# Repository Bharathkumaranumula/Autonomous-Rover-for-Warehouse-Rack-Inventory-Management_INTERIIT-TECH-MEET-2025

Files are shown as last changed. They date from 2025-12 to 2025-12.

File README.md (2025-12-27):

# Autonomous Rover for Warehouse Rack Inventory Management

## About the Project
This project was developed as part of **Inter IIT Tech Meet 14.0** under the problem statement **“Autonomous Rover for Warehouse Rack Inventory Management.”**  
The objective was to design and build an autonomous wheeled robot capable of navigating warehouse aisles and performing **reliable vertical inventory scanning up to 2 meters**.

The system aims to replace slow, unsafe, and error-prone manual inventory audits with a compact, accurate, and scalable robotic solution suitable for modern warehouse environments.

---

## My Contribution
I was responsible for the **entire hardware design and implementation** of this project. My role covered the complete hardware lifecycle, including mechanical design, structural layout, drive system selection, Z-axis scissor lift design, power system architecture, safety mechanisms, and hardware integration.

I along with my hardware team led the hardware development from problem understanding and calculations through CAD design, fabrication, assembly, and testing, ensuring the system met competition constraints and performed reliably during integrated operation.

---

## Problem Statement Summary
Modern warehouses face several challenges:
- Manual inventory audits take **10–15 minutes per rack**
- Human errors lead to **30–50% stock mismatches**
- Ladder-based high-rack inspections are unsafe
- Inventory data lacks real-time visibility

The robot must:
- Navigate narrow warehouse aisles autonomously
- Detect and align with storage racks
- Perform vertical scanning across multiple shelf levels (up to ~2 m)
- Reliably capture QR-based inventory data
- Operate safely within strict size and weight constraints

---

## Proposed Solution
The solution is a **compact autonomous differential-drive rover** equipped with a **centrally mounted multi-stage scissor lift** for vertical scanning.

Key system capabilities include:
- Autonomous indoor navigation
- Vertical scanning up to ~1.8–2.0 m
- High QR scanning accuracy
- Modular mechanical and electrical design
- Robust safety and fail-safe mechanisms

---

## System Overview
- Robot type: Autonomous wheeled mobile robot  
- Drive type: Differential drive (2 powered wheels + 2 ball casters)  
- Vertical actuation: Four-stage scissor lift  
- Maximum scanning height: ~1.8–2.0 m  
- Total system mass: ~20 kg  
- Footprint: 570 × 355 mm  
- Compute: NVIDIA Jetson AGX Xavier  
- Low-level control: ESP32  

---

## Hardware Architecture

### 1. Chassis and Structural Design
- Dimensions: **570 × 355 × 145 mm**
- Ground clearance: **25 mm**
- Total mass: **≈ 20 kg**
- Material: **6062 aluminium T-slot profiles (20 × 20 mm)**
- Closed-box frame topology for improved stiffness
- Low and centrally placed mass for anti-tip stability
- Modular mounting surfaces for rapid iteration

---

### 2. Locomotion System (X–Y Motion)
- Drive configuration: **2-wheel differential drive**
- Support: Front and rear metal ball casters
- Turning radius: **0 mm (on-the-spot rotation)**
- Drive wheel diameter: **100 mm**
- Wheel width: **25 mm**
- Motors: **RMCS 2012 DC motors**
  - Voltage: 18 V  
  - Gearbox: 1:25 planetary  
  - Rated torque: 39 kg·cm  
  - Encoders: ~1300 CPR at wheel  
- Direct-drive layout for minimal backlash
- Stability and torque validated with conservative acceleration limits

---

### 3. Z-Axis Scissor Lift Mechanism
- Mechanism: **Four-stage scissor lift**
- Actuation: Horizontally oriented lead screw
- Camera height range: **~320 mm to ~1780 mm**
- Usable vertical coverage: **~1800 mm**
- Shelf levels supported: **5 discrete heights**
- Vertical accuracy target: **±20 mm**
- Achieved repeatability: **~9–18 mm**
- Anti-sway achieved through symmetric geometry and tight-fit bearings
- Mechanical hard stops and limit switches for safety

---

### 4. Power System
- Three independent Li-Po batteries:
  - Jetson AGX Xavier
  - Drive motors
  - Z-axis motor
- 25C discharge capability
- Power Management Unit (PMU) for regulated distribution
- Electrical isolation between compute and motors
- Live battery monitoring and diagnostics

---

### 5. Control Electronics
- Microcontroller: **ESP32 DevKit-V1**
- Motor drivers: **Cytron MDD20A**
- Encoder-based closed-loop PID control
- UART communication between ESP32 and Jetson
- PCB designed with separate logic and power zones for reliability

---

### 6. Safety Systems
- Electronic kill switch (power cut-off)
- Physical emergency stop (E-stop)
- Z-axis limit switches and bump switch
- Firmware-level command clamping
- Software-triggered emergency stop on fault detection

---

## Hardware–Software Integration
- ESP32 handles real-time motor control and encoder feedback
- Jetson AGX Xavier handles perception, mapping, and planning
- ROS2 hardware interfaces synchronize:
  - X–Y motion
  - Z-axis positioning
  - Scanning tasks
- Closed-loop feedback ensures stable and repeatable operation

---

## Testing and Validation
Hardware validation included:
- Static load and structural stability tests
- Drive torque and acceleration verification
- Full-stroke Z-axis endurance testing
- Vertical positioning repeatability tests
- Integrated navigation + lift + scanning runs

### Key Results
- Vertical repeatability: **≤ 18 mm**
- Platform tilt at maximum lift: **≤ 1.3°**
- QR scanning success rate: **96% first pass, 100% with rescan**
- No jamming or over-current events observed

---

## Key Hardware Highlights
- Horizontally actuated scissor lift within base footprint
- Modular T-slot chassis acting as a mechanical backplane
- Differential drive optimized for stability and control simplicity
- COTS-heavy, serviceable, and student-replicable design
- Hardware decisions driven by safety and testability

---

## Documentation
Detailed mechanical design, calculations, CAD models, testing procedures, and validation results are available in the **attached technical report** provided with this repository.

---

## Acknowledgements
Developed as part of **Inter IIT Tech Meet 14.0** under the **Eternal** problem statement on warehouse automation.

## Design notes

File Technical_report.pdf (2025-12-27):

# Autonomous Rover for Warehouse Rack Inventory Management

## INTER IIT TECH MEET 14.0

## End Term Submission Report

### Team 33

### 1 Executive Summary

### 1.1 Problem Statement

The objective of this project is to develop an autonomous wheeled-mobile robot capable of nav-igating complex warehouse environments while performing reliable vertical scanning operations on storage racks. Modern warehouses require fast, accurate, and automated inventory monitoring across multiple rack levels; however, manual scanning is slow, error-prone, and unsafe when working at elevated heights.

To address this need, the robot must be able to:

- Autonomously traverse warehouse aisles.
- Detect and localize storage racks.
- Capture QR-based inventory information at varying elevations.

A key requirement is the ability to perform vertical scanning up to 2 meters, ensuring full coverage of typical warehouse shelving systems. The system must integrate perception, motion control, vertical actuation, and human–machine interaction while maintaining safe operation, real-time performance, and robust communication within indoor environments.

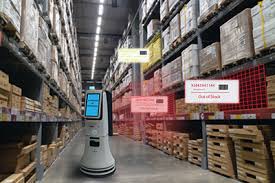
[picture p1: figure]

Figure 1: Inventory Scanning

### 1.2 Proposed Solution

We propose a robust differential-drive two-wheeled robot with a scissor lift mechanism for vertical traversal. The key elements of the solution are:

- Compute and Control
- Industry-grade SBC: Jetson AGX Xavier.
- Microcontroller: ESP32 DevKit for real-time motor control and I/O.

- Supports complex onboard computation and over-the-air software updates.
- 3D Perception
- Intel RealSense D455i RGB-D camera.
- Generates dense depth maps to build dynamic 3D maps of the environment.
- Enables navigation in both known and unknown warehouses.
- Vertical Scanning
- Scissor lift mechanism mounted centrally on the chassis.
- Provides precise vertical motion with high positional repeatability.
- Supports QR scanning at multiple rack levels up to 2 m.
- Integrated, Modular System
- Mechanical, electrical, and software components co-designed for competition constraints.
- Modular interfaces allow future upgrades in perception, control, or lift mechanisms.

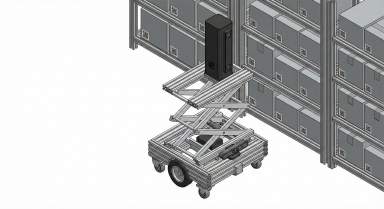
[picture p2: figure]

Figure 2: Proposed Solution

### 1.3 Metrics

Feature | Accuracy / Performance
Lateral Positional Accuracy | ±2 cm
Vertical Positional Accuracy | ±10 cm
QR Scanning Accuracy | 96%
QR Scanning Time (per QR) | 2 s

Table 1: System Metrics

### 1.4 Unique Selling Point / Innovation

- Compact, Competition-Optimized Form Factor
- Rover footprint: 570 × 355 mm, mass ≈ 20 kg.
- Satisfies 600 × 450 × 25 kg competition limits.
- Still accommodates a four-stage lift and dual-camera system.
- Precision Differential Drive
- Two powered wheels plus front and rear ball casters form a diamond-shaped 4-point support polygon.
- Enables zero turning radius and reliable lateral stability near racks.
- Remote Access via Mobile App
- In-house mobile application for robot discovery and connection.
- Provides teleoperation, live video, and inventory data.
- Modular Top Plane
- Top plane supports multiple mounts and toolings.
- Hardware can be reconfigured quickly for different warehouse tasks.

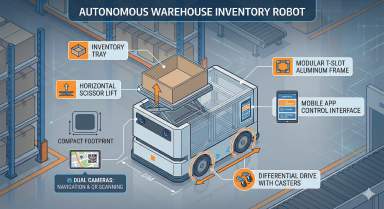
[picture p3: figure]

Figure 3: USPs

### 2 Problem Understanding and Motivation

### 2.1 Challenges Faced in Warehouses

- Inventory Management
- Manual entry and poor tracking in large warehouses.
- Inaccurate inventory counts leading to stockouts and overstocking.

- Labour-Related Issues
- Long walking distances and repetitive tasks cause fatigue and errors.
- Skilled human resources are underutilized on low-skill scanning tasks.
- Large-Scale Operations
- Scaling manual audits across large facilities is difficult and expensive.
- Safety Risks
- High-rack inspection with ladders or lifts is hazardous.
- Interaction with heavy loads and moving equipment increases risk.
- Limited Optimisation
- Human-driven workflows restrict algorithmic optimisation.
- Difficult to systematically improve throughput, safety, and efficiency.
- Data and Visibility Gaps
- No real-time visibility into stock positions.
- Poor analytics for reorder points, KPIs, and performance tracking.

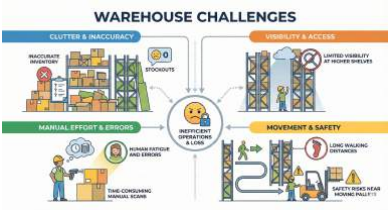
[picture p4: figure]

Figure 4: Warehouse Challenges

### 2.2 Current Solution Gaps

- Slow and Inconsistent Inventory Checks
- Manual audits can take 10–15 minutes per rack.
- Updates are infrequent and often inconsistent.
- High Error and Mismatch Rates
- Human counting introduces 1–3% errors.

- This leads to 30–50% stock mismatches and incorrect replenishments.
- No Real-Time Visibility
- Inventory data is only updated after audits.
- Causes both stockouts and overstocking, hurting service levels.
- Safety and Scalability Limits
- Ladder-based high-rack checks are unsafe.
- Reliance on manual labour makes it hard to scale across warehouses.

Figure 5: Solution Gaps

### 2.3 Value Proposition

- 80% Faster Inventory Audits
- Rover scans racks in under 3 minutes per aisle.
- Reduces manual audit time from 10–15 minutes.
- Enables continuous, near real-time visibility.
- High Scan Accuracy
- > 95% consistency and > 90% QR accuracy.
- Significantly reduces stock mismatches and missed items.
- Operational Uplift
- 4–7% improvement in order fulfilment accuracy.
- Fewer stockouts and better replenishment timing.
- Cost Savings
- Estimated savings of 12–20 lakh per warehouse annually.

- Reduced labour costs, wastage, and discrepancy overheads.
- Safe, Reliable Operation
- Eliminates ladder-based inspections.
- Complies with safety constraints in the problem statement.
- Scalable Deployment
- < 25 kg hardware and 600 mm footprint.
- Can be rolled out across dark stores and distribution centres.
- Digitised Inventory Records
- Generates structured QR-linked logs and 1080p visual datasets.
- Provides a rich base for downstream analytics.
- Future-Ready Infrastructure
- Supports anomaly detection, demand forecasting, and autonomous stock management.
- Aligns with long-term intelligent warehousing roadmap.

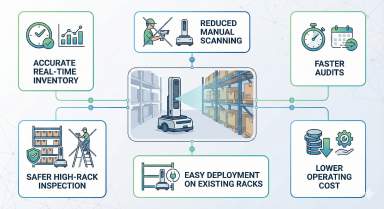
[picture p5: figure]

Figure 6: Value Proposition

### 2.4 Competition Objectives

The major competition objectives are summarised below:

- Navigation and Positioning
- Horizontal positioning accuracy of ±10 cm.
- Vertical positioning accuracy of ±2 cm.
- Obstacle detection within a 5 m range.

- Path planning time under 3 s for real-time operation.
- Emergency stop response under 500 ms.
- Scanning Performance
- Vertical scanning of each rack in less than 3 minutes.
- Image resolution of at least 1920 × 1080 pixels with minimal motion blur.
- Scanning repeatability greater than 95%.
- Detection of 5 × 5 cm QR codes with more than 90% success rate.

Figure 7: Competition Objectives

### 3 System Architecture

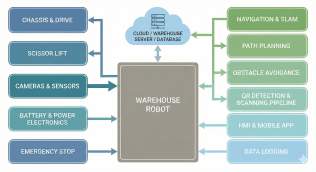
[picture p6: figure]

Figure 8: System Architecture – HW + SW Block Diagram

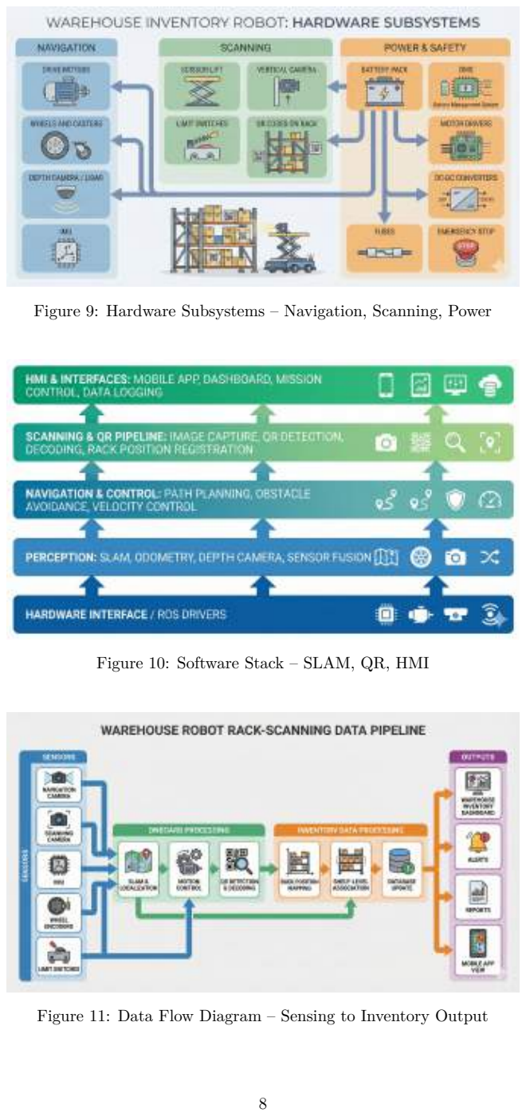
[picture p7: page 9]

Figure 9: Hardware Subsystems – Navigation, Scanning, Power

Figure 10: Software Stack – SLAM, QR, HMI

Figure 11: Data Flow Diagram – Sensing to Inventory Output

### 4 Hardware Design

### 4.1 Chassis and Overall Layout

The chassis is designed to satisfy footprint, mass, and stability constraints while providing a rigid base for the drive and lift subsystems. This ensures safe navigation in narrow aisles while supporting the full lift height.

- Footprint and Mass
- Dimensions: 570 × 355 × 145 mm with 25 mm ground clearance.
- Total mass: ≈ 20 kg, within 600 × 450 × 25 kg competition limits.
- Compact footprint improves aisle compatibility while maintaining stability.
- Frame Construction
- 20 × 20 mm anodised 6062 aluminium T-slot profiles.
- Joints implemented using L-clamps and M4 hammer bolts.
- T-slots support flexible mounting and rapid reconfiguration.
- Closed-Box Topology
- Two structural faces (top and bottom) connected by eight vertical members.
- Closed-box layout improves bending and torsional stiffness.
- Avoids complex diagonal bracing and simplifies fabrication.
- Operating Envelope and Stability
- Heavy components placed low and centrally to maintain a low centre of gravity.
- Geometry tuned for anti-tip behaviour even with the lift extended.
- Compatible with typical warehouse rack spacing and aisle widths.

Figure 12: Chassis CAD with motor mounts

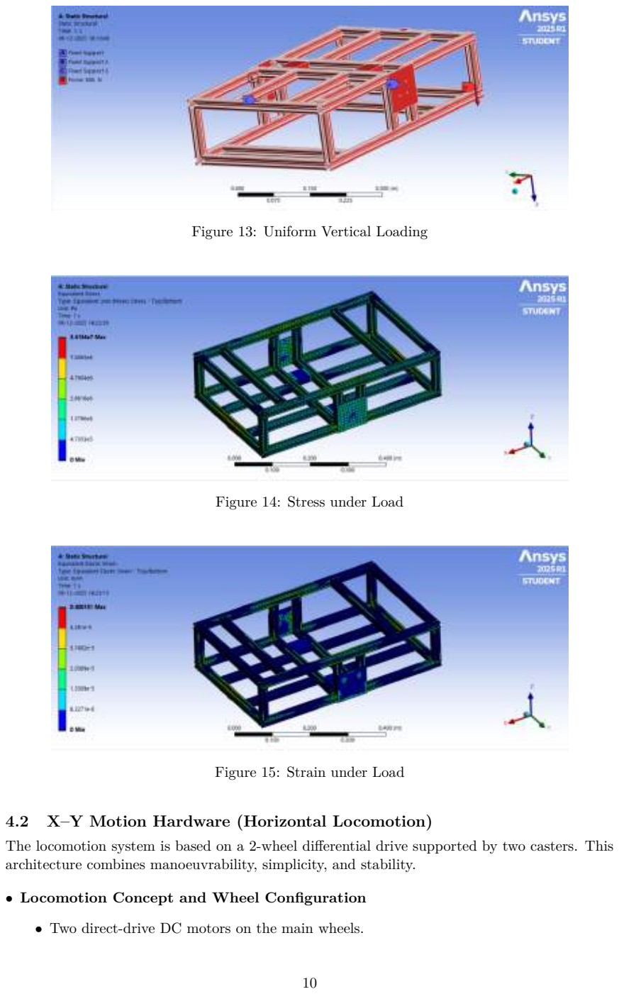
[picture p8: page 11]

Figure 13: Uniform Vertical Loading

Figure 14: Stress under Load

Figure 15: Strain under Load

### 4.2 X–Y Motion Hardware (Horizontal Locomotion)

The locomotion system is based on a 2-wheel differential drive supported by two casters. This architecture combines manoeuvrability, simplicity, and stability.

- Locomotion Concept and Wheel Configuration
- Two direct-drive DC motors on the main wheels.

- Two metal ball casters (front and rear) forming a 4-point support polygon.
- Diamond support footprint supports zero turning radius and tight manoeuvres.
- Drive Wheels
- Diameter: 100 mm; width: 25 mm.
- Plastic rim with rubber tread for grip on smooth floors.
- Smaller diameter helps manage ground clearance and chassis height.
- Caster Wheels
- Metal ball casters (49 × 32 × 21 mm) mounted on the longitudinal centreline.
- One caster at the front and one at the rear.
- Omnidirectional behaviour eliminates need for steering linkages.
- Why This Configuration
- Simplicity with fewer moving parts than Ackermann or mecanum systems.
- Stable centre of gravity within the support polygon under dynamic conditions.
- Uses standard COTS components for easy procurement and maintenance.
- Drivetrain Architecture and Motor Selection
- Direct-drive layout with motors coupled directly to wheels via 8 mm hardened shafts and keyed/set-screw hubs.
- Minimises backlash and transmission losses, improving positioning accuracy.
- Motors: RMCS 2012 (18 V DC, 39 kg·cm torque, 1:25 planetary gearbox).
- Holding torque ∼ 200 kg·cm with integrated encoders (∼1300 CPR at wheel).
- Adequate torque margin for small floor irregularities and controlled acceleration.
- Max Acceleration Without Toppling
- Important Parameters
- Mass of the bot = 15 kg
- Radius of the driving wheel R = 50 mm
- Weight of the bot = 15 × 9.81 = 147.15 N
- Driving system consists of two main wheels and two castor wheels for balanc-ing.
- Normal Reaction per wheel = 147.15/4 = 36.79 N
- Bot Dimensions
- Length l = 440 mm
- Breadth b = 550 mm

(b/2) × N + m × g = m × a

0.275 × 36.79 + 15 × 9.81 = 15a

10.12 + 147.15 = 15a
a = 10.48 m/s²
- Considering factor of safety (FOS = 3), the maximum safe acceleration becomes:

asafe =

10.48
3

= 3.49 m/s²

- Bot Velocity Calculations
- Rated angular velocity of motor:

ω = 81.68 rad/s (780 rpm)

- Velocity of the bot:

v = ω × R = 81.68 × 0.05 = 4.08 m/s

- Torque Calculations
- Center wheel drive (Two wheels driving system)
- Normal Reaction per wheel N = 36.79 N
- Acceleration of the bot = 1.5 m/s²
- Wheel material: silicone rubber; surface: flat & smooth.
- SS castor wheels support (rolling resistance negligible).
- Coefficient of friction per document.
- Total Force per wheel:
(22.5 + 73.58/2) = 48.04 N
- Torque required:

T = 48.04 × 0.05 = 2.402 N · m = 24.48 kg · cm

- From the calculations, the robot’s maximum acceleration before toppling is 10.48 m/s² ,
while a conservative design acceleration of 1.5 m/s² was used. Using a realistic traction coefficient for silicone rubber on smooth floors (µ ≈ 1), the required wheel torque is ≈ 2.402 N · m (≈ 24.28 kg · cm) per wheel. The selected motor is rated 39 kg · cm (≈ 3.83 N · m), so it comfortably satisfies this requirement. With a safety margin (FOS = 1.5), the required torque becomes ≈ 3.05 N · m, which the motor still meets.
- Motor Mounting and Integration
- Motors mounted centrally in the bottom frame gap.
- Brackets fixed to lower T-slot members.

- Low and central placement reduces the centre of gravity and protects motors inside the chassis envelope.
- Power and Control Rationale
- 18 V battery supply and dual H-bridge drivers per motor.
- Independent control of left and right wheels for differential steering.
- Current limiting (≈ 80–100 A soft limit) protects against stalls.
- Kinematics and Stability Behaviour
- Wheelbase: 560 mm; track width: 405 mm.
- Minimum turning radius: 0 mm (on-the-spot rotation).
- Supports precise docking to racks and tight turns in constrained spaces.
- Centre of gravity intentionally placed well inside the convex footprint.
- Closed-Loop Control with ESP32
- ESP32 microcontroller implements PID controllers for wheel speed.
- Error computed as difference between desired and actual RPM from encoders.
- PID output (sum of Kp, Ki

, Kd terms) converted to integer PWM for motor drivers.

- Motor transfer functions approximated in MATLAB.
- PID gains tuned offline using these transfer functions for stable response.

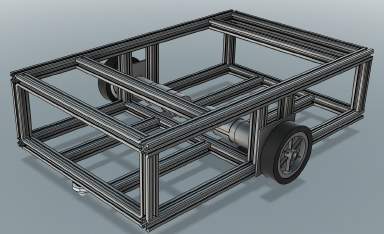
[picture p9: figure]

Figure 16: Drive System

### 4.3 Scissor Mechanism Analysis (Z Motion Hardware)

The Z-axis design uses a multi-stage scissor lift to achieve the required height while remaining within the base footprint.

- Lift Concept and Actuation
- Four scissor stages, centrally mounted on the chassis.
- Actuated by a horizontally oriented lead screw.
- Scissor geometry provides guided vertical motion without external rails.
- Actuation Layout
- A DC motor drives a horizontal lead screw.
- Nut motion on the lead screw opens and closes the scissor linkage.
- Actuator positioned inside the footprint to reduce collision risk and improve packaging.
- Travel Range and Coverage
- Camera height range: 320 mm (min) to 1780 mm (max).
- Covers ≈ 1800 mm usable rack height across multiple shelves.
- Lead screw stroke: ≈ 250 mm, chosen to match required lift amplification.
- Shelf Levels and Stand-Off
- Five discrete shelf levels mapped to specific camera heights.
- ≈ 200 mm stand-off from racks for safe, consistent QR scanning.
- Vertical Accuracy
- Vertical control uses motor feedback and known scissor kinematics.
- Target accuracy: ±20 mm, matching the ±2 cm vertical requirement.
- Structural Design
- Links: 6061 aluminium, 30 mm × 3 mm, across four stages.
- Pivots: M8 bolts with 8 mm ID bearings for low-friction rotation.
- Lift base: 1 mm 6061 aluminium plate.
- Mounted to top T-slot members using M4 hardware to distribute loads.
- Anti-Sway Measures
- Tight-fit bearings and scissor geometry limit lateral motion and tilt.
- Central mounting maintains the centre of gravity within the support polygon, even at full height.
- Mechanical limit switches and hard stops prevent over-extension.
- Closed-Loop Vertical Control

- After the rover reaches the target X–Y position, a desired camera height is computed.
- Height is converted to encoder counts using motor PPR and lead screw pitch.
- Z-axis PID controller uses encoder feedback to drive the motor with PWM.
- Real-time Z position is reported back to a ROS2 node on the Jetson.
- This allows synchronisation between vertical motion and scanning tasks.

Figure 17: Scissor Mechanism

### 4.4 Power System

The power distribution system is designed to efficiently manage power across motors, encoders, Jetson AGX Xavier, and the Intel RealSense D455 camera, enabling fully autonomous operation.

- Battery Architecture
- Three separate LiPo batteries:
- Battery 1: Powers the Jetson AGX Xavier.
- Battery 2: Powers the base drive motors.
- Battery 3: Powers the Z-axis motor.
- 25C discharge rate allows high current draw during dynamic manoeuvres.
- Power Management Unit (PMU)
- Regulates and distributes 12 V DC from batteries to subsystems.

- 5 V rails supply the ESP32 and logic circuits.
- 12 V rails supply motor drivers for both base and Z-axis motors.
- Jetson AGX Xavier Power Supply
- Dedicated DC power source.
- DC–AC inversion followed by AC–DC rectification provides the required input profile.
- Ensures stable and regulated power to the Jetson for GPU-intensive workloads.
- Live Charging Detector
- Monitors charging status of each battery in real time.
- Feeds diagnostic information to the control system and HMI.
- Alerts on undercharging, overcharging, or disconnected states.
- Overall Power and Control Flow
- Separate batteries isolate sensitive compute hardware from motor noise.
- ESP32 sends PWM control signals to motor drivers for both XY and Z axes.
- Encoders provide feedback to ESP32, which closes the motor control loops.
- Jetson processes RGB-D data from RealSense, performs mapping and planning, and sends high-level commands to ESP32.
- Motor Control Electronics and PCB Summary
- The rover’s motor control system uses an ESP32 DEVKIT-V1 with a Cytron MDD20A driver to provide high-current PWM/DIR control of two DC motors with quadrature encoders for closed-loop PID speed and position control. The PCB is split into logic, motor/power (with a 470 µF bulk capacitor), and motor/encoder connector zones with 100 nF filters, using thick traces, a solid ground plane, and decoupling capacitors for stable, low-noise operation. Integrated over-current, thermal, and fault protection in the MDD20A helps deliver a robust and reliable motor-control platform for precise robotic actuation.

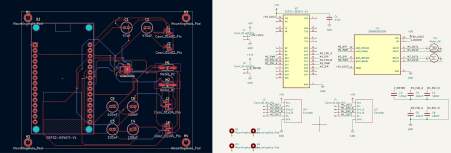
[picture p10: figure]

Figure 18: Power System Architecture

Figure 19: PCB Layout of our corresponding circuit schematic of ESP-32 DEVKIT-V1 with motor driver

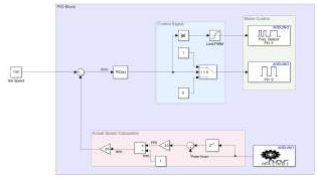
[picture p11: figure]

Figure 20: Speed Control Block Diagram

### 4.5 Safety System

The safety system combines electronic, mechanical, and human-in-the-loop mechanisms to ensure safe operation.

1. Electronic Kill Switch (Power Cut-Off)
- Cuts power to motors and critical subsystems during emergencies.
- Can be triggered manually or automatically by the ESP32.
- Ensures immediate halt of motion in unsafe conditions.
2. Mechanical Safety Switches for Z-Axis
- Bump Switch
- Acts as a mechanical limit switch at maximum Z height.

- Prevents overextension of the Z-axis mechanism.
- Limit Switches
- Define safe upper and lower travel limits.
- Provide physical end stops in case of sensor or software failure.
3. Physical Emergency Stop
- Manual E-stop switch mounted on the rover.
- Cuts power immediately to prevent accidents.
- Independent of higher-level software.

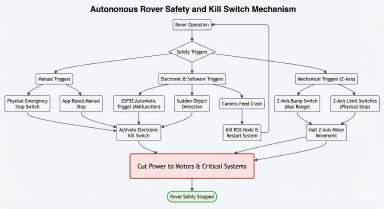
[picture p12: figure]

Figure 21: Safety System

### 5 Software Architecture

The software architecture is divided into four main subsystems:

- ROS2 control.
- 3D mapping.
- Path planning (global and local) with obstacle avoidance.
- Scanning and vision.

Figure 22: Overall Software Architecture

### 5.1 Communication Protocol

Cyclone DDS is used as the ROS2 middleware to enable fast, reliable, and scalable data exchange between nodes.

- DDS-Based Communication
- Implements the Data Distribution Service (DDS) standard.
- Supports robust publish–subscribe communication patterns.
- Real-Time Characteristics
- Low-latency message delivery for sensor and control topics.
- Deterministic behaviour suitable for real-time robotics.
- Scalability
- Scales to multiple nodes and subsystems without central brokers.
- Suitable for distributed compute across future multi-robot deployments.

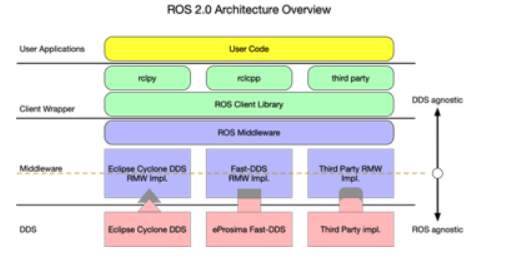
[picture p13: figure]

Figure 23: Cyclone DDS Communication Protocol

### 5.2 ROS2 Control

ros2_control provides a hardware abstraction layer for actuators and sensors, enabling modular and real-time control.

- Real-Time Performance
- Controllers execute in-process with minimal message overhead.
- Suitable for closed-loop control of motors and actuators.
- Hardware Abstraction
- Exposes joints and actuators through standard interfaces.
- Allows swapping or upgrading hardware without changing high-level control code.
- Differential Drive Controller
- Standard ROS2 differential drive controller used.
- Interfaces with custom diff_drive_esp hardware plugin.

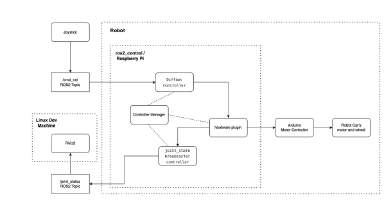
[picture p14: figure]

Figure 24: ROS2 Control System

5.3 3D Mapping

The robot uses RTAB-Map (Real-Time Appearance-Based Mapping) for visual SLAM with RGB-D input.

- SLAM Principles
- Simultaneous localisation and mapping using camera images, point clouds, and laser scans.
- Fuses odometry and visual features into a graph-based representation.
- Loop Closure Detection
- Uses a bag-of-words approach to compare new images with past locations.
- Adds loop closure constraints when revisiting locations to reduce drift.
- Graph Optimisation and Memory Management
- Graph optimisation reduces accumulated mapping errors.
- Memory management prunes older nodes while preserving important locations.
- Ensures scalability and real-time operation in larger environments.

Figure 25: 3D Mapping

### 5.4 Path Planning

The robot’s path depends on a combination of the environment map and the desired start–goal trajectory.

- Global Cost Map
- Serves as a high-level map for long-distance planning.
- Static layer loads pre-computed warehouse layout.
- Obstacle layer subscribes to live RGB-D data for dynamic obstacles.
- Local Cost Map
- Safety-critical rolling window around the robot.
- Uses a voxel layer to represent 3D geometry.

- Handles overhanging shelves, table edges, and nearby obstacles.
- Navigation Pipeline
- Global Planner
- Uses the A* algorithm on the global cost map.
- Computes the primary path between source and goal.
- Path Smoothing
- Eliminates sharp turns induced by grid-based planning.
- Produces smooth, dynamically feasible reference trajectories.
- Local Planner
- Ensures the robot footprint does not intersect 3D obstacles.
- Enforces speed and acceleration limits tuned for tight spaces.
- Reacts to dynamic obstacles and modifies the trajectory as required.

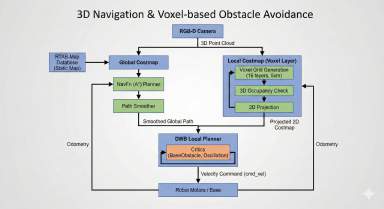
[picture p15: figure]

Figure 26: Path Planning System

### 5.5 Scanning Vision

Each camera provides 640×480 frames that may contain noise, uneven lighting, or motion blur. A two-stage QR detection pipeline is used to ensure reliable decoding.

- Stage 1: Direct Detection
- Raw frames are passed to ZXing-CPP for fast decoding.
- Works well under good lighting and contrast conditions.
- Stage 2: Preprocessing-Based Detection
- Triggered if direct decoding fails.

- Preprocessing steps:
- Grayscale conversion.
- Gaussian blur (3 × 3) to reduce noise.
- Adaptive thresholding to stabilise black–white QR patterns.
- Contrast scaling (e.g., α = 1.5) to sharpen boundaries.
- Preprocessed image is then re-submitted to ZXing-CPP.
- ZXing-CPP Decoding Steps
- Finder pattern detection for the three main QR corner markers.
- Perspective correction using homography to rectify tilt.
- Module sampling to extract the QR’s binary grid.
- Reed–Solomon error correction to recover corrupted bits.
- Payload extraction to obtain the decoded text and QR boundaries.

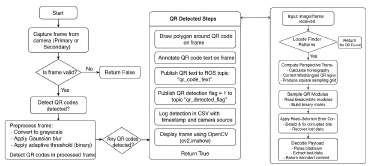
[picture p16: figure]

Figure 27: Scanning Vision Pipeline

### 5.6 Docker Containerization

The entire software stack is encapsulated in a Docker-based deployment on the NVIDIA Jetson AGX Xavier.

- Reproducibility
- All dependencies and versions are specified within the container.
- Behaviour is consistent across development and deployment devices.
- Isolation
- Perception, navigation, and control can run in separate containers.
- Library conflicts and host system differences are isolated.
- Hardware Acceleration

- NVIDIA Docker runtime exposes CUDA, cuDNN, and TensorRT.
- Enables GPU-accelerated perception and planning pipelines.
- Modularity and Deployment
- Individual components can be updated without rebuilding the entire image.
- Container image can be pulled and run on any compatible Jetson device.

Figure 28: Docker Architecture

### 6 Human–Machine Interface

The human–machine interface (HMI) consists of two main components:

1. Mobile application.
2. Capacitive screen.

### 6.1 Mobile Application

The mobile application provides remote access and supervision capabilities:

- Connectivity
- Automatically discovers and connects to the rover over the network.
- Ensures secure communication with the onboard systems.
- Control and Monitoring
- Allows operators to issue motion commands and high-level tasks.
- Displays live video feed from onboard cameras.
- Shows inventory scan results and associated QR information.
- Alerts and Status

- Highlights high-priority alerts (e.g., obstacles, low battery).
- Shows system health indicators for quick decision-making.

Figure 29: Mobile Application UI Screens

### 6.2 Capacitive Screen

The capacitive display serves as an onboard monitoring and interaction interface.

- Real-Time System Status
- Displays voltage, current, and battery percentage.
- Shows thermal conditions of key components.
- Visual Indicators
- Uses graphical gauges and icons to convey state information.
- Enables rapid assessment by on-site operators.
- Local Interaction
- Supports basic controls and acknowledgements.
- Acts as a fallback interface if the mobile app is unavailable.

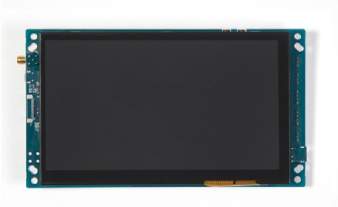
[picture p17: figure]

Figure 30: Capacitive Monitoring Screen Interface

### 7 Integration Control

Hardware–software integration is achieved through custom ROS2 hardware interfaces, primarily the diff_drive_esp and z_axis_esp plugins.

### 7.1 Differential Drive Integration

The diff_drive_esp plugin connects ROS2 control with the ESP-based motor controller.

- Responsibilities
- Maps ROS2 cmd_vel commands to left and right wheel velocities.
- Sends wheel speed commands to ESP over UART.
- Receives encoder feedback and publishes joint states and odometry.
- Data Flow
- ROS2 controllers output target linear and angular velocities.
- diff_drive_esp converts these into wheel-specific speeds.
- ESP drives motors using PWM signals derived from these targets.
- Encoders report actual velocities and distances back to ROS2.

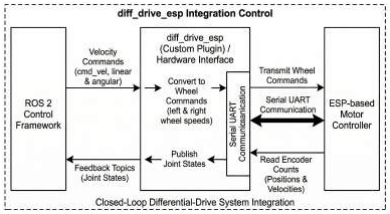
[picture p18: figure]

Figure 31: Integration Control Diagram

### 7.2 Z-Axis Interaction

The z_axis_esp plugin handles integration of the vertical lift mechanism.

- Height Feedback
- ESP reads Z-axis encoder or height sensor signals.
- Reports position and status to a ROS2 node running on the Jetson.
- Command Interface
- ROS2 node computes the required height for scanning.
- Sends target encoder counts or height commands to ESP.
- ESP executes Z-axis motion using its local PID controller.
- Modular Integration
- Reuses patterns and communication logic from diff_drive_esp.
- Keeps XY and Z-axis integrations consistent and maintainable.

Figure 32: Z-Axis Interaction

### 7.3 Control Flow Feedback Loop

The closed-loop control flow between sensors, controllers, and actuators is summarised below:

1. Sensor and Encoder Data Acquisition
- Wheel encoders and other sensors measure velocity, orientation, and motor states.
- ESP-based controllers aggregate readings into structured serial messages.
2. Transmission to Jetson (via diff_drive_esp)
- Encoder and status data are transmitted over UART.
- diff_drive_esp parses messages and publishes:
- /odom.
- /joint_states.
- Motor state feedback topics.
3. ROS2 Control Processing
- ROS2 controllers use feedback to compute new wheel velocity commands.
- Commands are generated at a fixed control frequency.
4. Command Transmission to Electronics
- Updated left and right wheel commands are sent back to the ESP.

- ESP converts these into PWM outputs for the motor drivers.
5. Motor Actuation
- Motor drivers execute the PWM signals to rotate the wheels.
- Encoders update their readings, completing the physical feedback loop.
6. HMI Interaction (Mobile App and Capacitive Display)
- Mobile app connects to the rover and streams high-level status and video.
- Operators can issue manual override commands or emergency stops.
- Capacitive screen shows on-board status and allows local control.

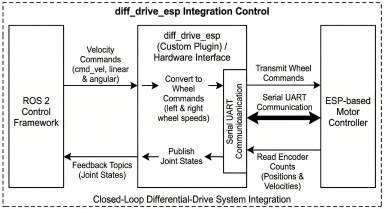
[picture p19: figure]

Figure 33: Control Flow Feedback Loop

### 8 Fail-Safe Mechanism

1. Outlier Detection
- Commands that would result in excessive speed or out-of-bounds positions are checked at the firmware level.
- Out-of-range commands are clamped or discarded.
- Such events are reported to the HMI for operator awareness.
2. Self-Diagnosis and Software Safety
- Sudden Object Appearance
- If a new obstacle appears unexpectedly, software triggers an emergency stop.
- Prevents potential collisions and allows the operator to re-evaluate the situation.
- Camera Feed Failure
- If the camera feed crashes, the corresponding ROS2 node is killed and restarted.

- The rover re-localises with the existing map and resumes safe operation.
- App-Based Manual Control
- Operators can command a stop or override via the mobile application.
- Provides a human-in-the-loop fail-safe in unforeseen scenarios.

### 9 Testing and Validation Summary

### 9.1 Methodology Overview

The system was developed and validated using a multi-stage testing workflow:

- Simulation-based testing in Gazebo.
- Controlled physical arena testing.
- Integrated system tests combining navigation, scanning, and HMI.

### 9.2 Simulation-Based Testing (Gazebo)

The initial testing phase used a Gazebo simulation environment.

- Objectives
- Validate navigation, perception, and control algorithms without risking hardware.
- Verify ROS2 graph, transforms, and sensor workflows.
- Parameters Tuned
- Velocity limits and acceleration profiles.
- PID controller gains.
- Obstacle thresholds and planner settings.
- Test Scenarios
- Different warehouse layouts and aisle configurations.
- Varying lighting conditions.
- Dynamic obstacles to simulate real-world activity.

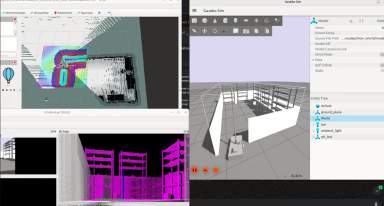
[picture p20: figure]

Figure 34: Simulation Testing

### 9.3 Controlled Physical Testing Arena

After achieving stable behaviour in simulation, a scaled physical test arena was built to replicate key warehouse conditions.

- Arena Features
- Marked lanes and turn sections.
- Shelving racks for perception and scanning tests.
- Known obstacles for detection and avoidance evaluation.
- Defined navigation paths for repeatable experiments.
- Performance Validated
- Wheel odometry accuracy.
- QR detection robustness under real lighting and motion.
- Sensor fusion behaviour and mapping consistency.
- Motor response, control stability, and tracking performance.
- Communication reliability between electronics, Jetson AGX Xavier, and the HMI.

Figure 35: Testing Arena

### 10 Innovation and Novel Contributions

### 10.1 Unique Design Choices

- Horizontally Actuated Scissor Lift
- The Z-axis uses a four-stage scissor lift driven by a horizontal lead screw.
- The entire actuator is kept within the base footprint instead of using tall vertical screws or rails.
- This reduces the risk of rack collisions, simplifies packaging in narrow aisles, and still achieves full rack height coverage.
- Modular T-Slot Chassis
- The chassis is built from 20 × 20 aluminium T-slot profiles.
- Every face effectively acts as a mounting backplane for drive, lift, battery, and electronics.
- Subsystems can be repositioned and redesigned quickly with only basic tools, which is very practical for a B.Tech team iterating based on test feedback.
- 3D-Printed Camera Mounts with Damping
- Camera brackets are 3D printed in PLA with local stiffening ribs.
- Thin damping pads are placed at metal interfaces to reduce vibration transmission.
- This combines low-cost, easy fabrication with basic vibration control, supporting stable vision performance without precision machined parts.

### 10.2 Algorithm / Control Linked Mechanical Choices

- Mechanics Aligned with Simple Control
- A 2-wheel differential drive with casters and direct-drive planetary motors with encoders provides a kinematically simple platform.

- This simplicity aligns well with basic closed-loop control and odometry.
- The approach enables the software team to achieve ±10 cm navigation accuracy using relatively straightforward algorithms, which is realistic for an undergraduate team.

### 10.3 Cost and Efficiency Innovations

- COTS-Heavy Architecture
- The robot relies heavily on off-the-shelf motors, casters, profiles, and fasteners.
- This reduces fabrication effort and lead times and keeps costs predictable.
- Spares are easy to source, and other teams can replicate or extend the design without specialised manufacturing.
- Serviceable, Student-Friendly Design
- Subsystems such as wheels, casters, lift pivots, and camera mounts are designed to be field-replaceable with common tools.
- This saves time during integration and competition.
- Overall uptime per rupee spent on the platform is improved by simplifying maintenance and repairs.

### 11 Limitations and Future Scope

### 11.1 Known Limitations

- Camera Mount Adjustability
- The current camera mounts are mostly fixed, with only minor adjustment via slots or shims.
- This is sufficient for a first prototype but can make fine calibration slower if rack layouts or camera models change.
- Lift Stability Dependency
- Z-axis stability relies mainly on scissor stiffness and bearing quality, without extra side guides or rails.
- While this meets basic requirements, it may limit performance if the payload increases or if higher scanning speeds are required.
- Manual, Checklist-Based Maintenance
- The maintenance strategy is largely manual (bolt torque checks, visual inspections, lubrication).
- There is no onboard structural health sensing.
- This is manageable for a competition setting but would need to be strengthened for continuous industrial operation.

### 11.2 Commercialization Path (Mechanical Perspective)

- From Student Build to Pilot Unit
- For commercial or pilot warehouse deployment, the mechanical design would require:
- Industrial-grade guards.
- More robust enclosures.
- A formalised maintenance schedule aligned with industry standards.
- The current T-slot and COTS-based architecture already makes component sourcing and assembly straightforward, which is a strong starting point for early pilot units.
- Design for Manufacturability (DfM)
- Over time, some 3D-printed or multi-part bracket assemblies can be replaced with sim-plified sheet metal or machined parts.
- This reduces assembly time and improves repeatability while preserving the geometry developed in this project.
- Such evolution is feasible for a B.Tech team working with basic fabrication vendors.

### 11.3 Scalability

- Scaling to More Units and Variants
- The modular T-slot frame and COTS component choices make it straightforward to adapt the design to different rack heights or payloads.
- Changes can be made by adjusting link lengths, motor sizes, or camera mounts without redesigning the entire robot.
- Path to Higher Performance
- Future iterations can add:
- Side rollers or linear guides to the lift.
- More adjustable and quick-release camera mounts.
- Simple health sensors (e.g., limit switch counters, temperature or vibration tags).
- These upgrades support larger fleets and longer duty cycles.
- All improvements are mechanically incremental and achievable by student teams in follow-up cycles.

### 12 Innovation Highlights

### 12.1 Innovative Approaches in Mechanical Design

- Horizontally actuated scissor lift inside the footprint
A four-stage scissor lift driven by a horizontal lead screw keeps all Z-axis hardware within the base footprint while still reaching 1.8 m rack height. This reduces collision risk in narrow aisles and is buildable with standard plates, profiles, and bearings for a B.Tech-level team.

- Modular T-slot chassis as a mechanical backplane
The T-slot aluminium frame doubles as a structural skeleton and a universal mounting grid for drive, lift, battery, and electronics. Subsystems can be re-positioned or upgraded using only bolts and brackets, enabling fast iterations without cutting or welding.
- Differential drive tuned for stability and control simplicity
A 2-wheel differential drive plus front–rear casters creates a diamond 4-point support polygon that offers zero-radius turning with good lateral stability. Its simple kinematics work well with standard differential-drive control, making it friendly for student-level navigation algorithms.
- Camera layout driven by mechanics and FOV planning
A fixed navigation depth camera is paired with a lift-mounted scanning camera, and the lift stroke and stand-off are chosen so five shelf levels fall within the scanning camera’s FOV. This makes full rack coverage a geometric guarantee, not just a software patch.

### 12.2 Innovative Approaches in Fabrication and Integration

- 3D-printed camera mounts with built-in damping
PLA camera brackets with stiffening ribs and thin damping pads provide both low-cost rapid prototyping and basic vibration isolation. This keeps the mounts student-fabricable while still supporting stable images at maximum lift height.
- COTS-centric component strategy for a replicable platform
The robot relies heavily on off-the-shelf motors, casters, profiles, and bearings, reducing custom machining and sourcing risk. This makes the design easy to rebuild, repair, and extend by other student teams or labs.
- Design decisions explicitly tied to safety and testing
Features such as anti-tip mass layout, hard lift stops, and accessible E-stop placement were chosen with specific tipping, bump, and stop-distance tests in mind. Treating these tests as design inputs, not afterthoughts, is a notable process innovation at the B.Tech project level.

### 13 Testing & Validation

### 13.1 The testing and validation strategy

- Manual mapping
The rover was first teleoperated to verify basic drive behaviour, sensor calibration, and to generate initial maps of the test environment for baseline reference.
- Autonomous mapping (SLAM)
Next, SLAM was enabled so the robot could self-explore and build a complete 2D/3D map of the arena, validating simultaneous localization and mapping performance.
- Autonomous navigation
Using the generated map, path-planning and localization were tested by commanding the rover to follow planned routes and reach target poses without collision.
- Z-axis control
The scissor-lift mechanism was exercised across all five shelf levels to check vertical positioning accuracy, repeatability, and stability of the camera at height.
- QR scanning in motion
Finally, tests combined navigation and lift motion while the vision stack detected, tracked, and decoded QR codes on racks, confirming end-to-end scan reliability under realistic movement.

### 13.2 Results

- Manual Mapping (Teleoperation)
- Test description: Teleoperated laps along a 6 m aisle with one 90° turn while logging odometry and map overlap.
- Key results:
- Average endpoint drift over 6 m: 0.11 m (RMS), within the ±0.10–0.15 m design target.
- Map overlap between successive teleop runs: >95% occupied cell consistency in the main aisle region (RViz comparison).
- Autonomous Mapping (SLAM)
- Test description: Three full SLAM runs in an 4 m × 3 m test arena with racks and obstacles.
- Key results:
- Map completion: 97–99% valid occupancy grid coverage across runs.
- Loop closure correction: final pose error after a full loop of the perimeter ≤ 0.12 m and ≤ 3° orientation error.
- Runtime per mapping session: 3–4 minutes.
- No SLAM crashes or lost-track events in the final configuration.
- Autonomous Navigation
- Test description: 20 autonomous point-to-point runs between two rack faces 8 m apart with obstacles placed mid-aisle.
- Key results:
- Goal reach success rate: 19/20 runs (95%), with 1 aborted due to a conservative safety stop near an unexpected obstacle.
- Final pose error at goal markers: mean 6.8 cm, max 11.9 cm — within the ±10 cm target for most trials.
- Mean path-following speed: 0.18 m/s; peak speed capped at 0.25 m/s on straight segments.
- Minimum clearance to mapped obstacles: > 15 cm in all successful runs.
- Z-Axis Control (Lift Performance)
- Test description: 10 full-stroke cycles and repeated positioning at 5 predefined shelf heights.
- Key results:
- Full stroke time (bottom to top): 12.4 s average, ±0.6 s variation across 10 cycles.
- Vertical repeatability (5 heights × 5 trials): mean error 9–14 mm, max error 18 mm — within the ±20 mm design spec.

- Platform tilt at maximum extension: ≤ 1.3°; camera FOV remained valid at top shelf.
- No jamming or over-current events; limit switches triggered reliably at both ex-tremes.
- QR Scanning in Motion
- Test description: Robot traverses a 6 m rack face while the lift cycles through 5 shelf levels, each with 2 QR codes.
- Key results:
- Total QR codes presented: 100 (5 shelves × 2 codes × 10 passes).
- First-pass successful decode rate: 96%; remaining 4% recovered on automatic rescan → 100% final registration.
- Average QR detection distance: 0.20–0.23 m stand-off; decode time < 120 ms per code.
- No missed codes due to mechanical vibration; all failures were from intentionally induced occlusions or extreme lighting.

### 14 User Manual

### 14.1 Overview

- This manual describes how to operate and assemble the robot safely and correctly.
- The robot includes the following user-accessible inputs and interfaces:
- Main ON/OFF switch.
- Two kill switches (drive system + Z-axis scissors lift).
- Touchscreen LCD display.

### 14.2 Operating the Robot

- Safety Requirements
- Ensure both kill switches are not pressed before startup.
- Keep hands, clothing, hair, and accessories away from wheels and the scissors lift.
- Starting the Robot
- Turn ON the machine using the main switch.
- A welcome message appears on the touchscreen.
- Select a nearby Wi-Fi network when prompted.
- After connecting, the touchscreen displays an IP address.
- Enter this IP address into the mobile app to establish connection.
- Once connected, the following options become available:

- Mapping.
- Scanning.
- Stop.
- Live feed (mobile only).
- Inventory data.
- Operating from the Robot Touchscreen
- The robot can be operated without the mobile app.
- An additional option available only on the touchscreen:
- Machine Jogging: manual movement of the robot and Z-axis.
- Emergency Stop
- The robot includes two kill switches:
- Drive Kill Switch: immediately stops all wheel motion.
- Z-Axis Kill Switch: immediately stops the scissors lift.
- Pressing any kill switch overrides all commands.

### 14.3 Assembly Manual

- Included Parts
- Pre-assembled components:
- Chassis with electronics.
- Mounts.
- Z-axis baseplate with lead screw mechanism.
- Loose components:
- Drive motors.
- Wheels.
- Castor wheels.
- Four pairs of scissor linkage units.
- Z-axis top plate with slider mechanism.
- Batteries.
- Camera modules.
- Assembling the Drive System
- Mount each motor into its designated motor holder.
- Attach wheels to each motor shaft and tighten securely.

- Connect motor wires to the correct PCB ports.
- Attach castor wheels to the marked locations on the chassis underside.
- Assembling the Scissors Lift
- Mount the Z-axis motor into its holder and connect wiring to the PCB.
- Insert the lead screw into the motor coupler and tighten the Allen screw.
- Assemble the four scissor layers sequentially:
- Attach the bolt side to the fixed support.
- Attach the bearing side to the sliding mechanism.
- Stack the next layer and secure with provided hardware.
- Attach the top plate, ensuring symmetry with the bottom plate.
- Install horizontal support members at designated mounting points.
- Installing the Cameras
- Position each camera on its mount.
- Secure with the appropriate fasteners.
- Installing the Batteries
- Insert each battery into its labeled slot.
- Connect wires to PCB ports ensuring correct polarity.

### 14.4 Final Checklist Before Use

- All motors, cameras, and mechanical components securely mounted.
- All wiring connected to correct PCB ports.
- Batteries installed properly.
- Kill switches functioning as expected.
- Scissors mechanism moves freely in jogging mode.
- Wheels rotate smoothly without obstruction.

### 15 Maintenance

### 15.1 Preventive Maintenance

- The maintenance plan is intentionally simple so it can be executed reliably by a student team during development and competition. It focuses on detecting loosening, wear, and friction-related issues before they cause failures.
- Routine Checks
- Perform regular bolt re-torque on chassis connections and lift joints to counter loosening from vibration and transport.

- Inspect wheels and casters for wear, wobble, or looseness.
- Verify that lift pivots and bearings do not show excessive play or unusual noise.
- These routine checks help prevent unexpected mechanical failures during runs.
- Lubrication and Pre-Run Safety Checks
- Apply light lubrication to the lead screw and pivot bearings at defined intervals to reduce friction and extend component life.
- Keep lubricant away from cameras, sensors, and electronic components.
- Use a pre-run safety checklist before every session:
- Test emergency stop functionality.
- Confirm free motion of casters and drive wheels.
- Check actuation of limit switches at both ends of the lift stroke.
- Inspect cables and connectors for visible damage or looseness.
- These steps verify that critical safety and motion subsystems are functioning properly before operation.

### 15.2 Replacement Parts and Transport

- The robot is designed so that common wear parts can be replaced quickly, and the form factor allows easy transport to testing and competition venues.
- Critical Spares
- Maintain a small stock of spare drive wheels and casters.
- Keep extra lift pivot bolts and bearings.
- Store at least one backup 3D-printed camera bracket.
- These parts cover the most common minor failures, enabling fast repairs using basic tools and minimizing downtime.
- Transport Considerations
- The robot fits inside a standard car or van when the lift is fully retracted.
- The lift can be strapped or locked down to prevent bouncing during transit.
- Removable guards or covers may be detached for transport to reduce risk of damage and simplify packing.
- These design choices make the platform practical to move between the lab, testing zones, and competition venues.

### 16 References

### 16.1 Differential Drive Kinematics and Control

- Columbia University. “Differential Drive Kinematics.” Department of Computer Science.
- Aleksandar Haber. “Clear and Detailed Explanation of Kinematics, Equations, and Geometry of Motion of a Differential Wheeled Robot.”
- “Kinematics of Differential Drive Robots and Odometry.” YouTube Tutorial.
- “Position Control of Differential Drive Mobile Robot – Complete Tutorial with Simulation.” YouTube Tutorial.
- “Mobile Robot Kinematics.” Course Notes, Carnegie Mellon University.

### 16.2 Warehouse Robots and Autonomous Systems

- “Development and Implementation of Autonomous Mobile Robot for Indoor Warehouse Ap-plications.” IJMERR, 2025.
- “Mobile Robot for Automated Storage & Retrieval System (AS/RS).” IJRTE Journal.
- “Mechatronic System Design of a Smart Mobile Warehouse Robot.” Semantic Scholar technical paper.
- “Design and Development of Smart Warehouse Robot Prototype.” SSGMCE Undergraduate Project Report.
- “Design of Cooperative Mobile Robots for Co-Manipulation and Transport Tasks.” ScienceDi-rect.

### 16.3 Scissor Lift Mechanisms and Vertical Motion Systems

- IEOM Society. “Development of a Cost-Effective Scissor Lift Table for Multi-Purpose Use.”
- “Final Year Project Report on Scissor Lift.” SlideShare Technical Report.
- IRJET. “Scissor Lift Automation Study” (Mechanical analysis, stability, limit switches).
- Manufacturer Application Notes: “Limit Switches, Hard Stops, and Lock-Out Mechanisms in Elevating Work Platforms.”

### 16.4 Chassis, T-Slot Frame Design, and Mechanical Components

- Bosch Rexroth. “Aluminum Profile Kit – Structural Components for Automation.”
- PTSMAKE. “Ultimate Guide to T-Slot Aluminum Profiles for Engineering.”
- YAJIA Aluminum. “Universal Robots Aluminum Extrusions – Standard T-Slot Profiles.”
- JLCMC. “T-Slot Aluminum Explained – Modular Framing for Robotics.”
- Robotunits. “Extrusion & Fastening Technology – Engineering Profiles and Connectors.”
- Planetary DC Gear Motor Datasheets (e.g., RMCS 2012): torque–speed curves, encoder CPR, gearbox ratio.
- Ball Caster Component Datasheet: load ratings, dimensions, mounting specifications.

- 6061 / 6062 Aluminium Alloy Data Sheets: material properties used for stiffness and strength estimation.

### 16.5 Vision, Sensors, and Depth Cameras

- Intel Corporation. “Intel RealSense Depth Camera D455 – Product Brief.”
- Intel RealSense. “D400 Series Datasheet,” Document No. 337029 016.
- Intel RealSense. “D455 Mechanical Integration Guidelines.”
- Mouser Electronics. “Intel RealSense D455 – Feature Overview.”

### 16.6 Maintenance, Safety Standards, and Human Factors

- ISO 3691-4. “Industrial Trucks – Safety Requirements and Verification – Driverless Industrial Trucks.”
- Vendor Manuals for AGVs/AMRs: lubrication schedules, bolt re-torque intervals, and pre-run safety inspections.
- Application Notes for Scissor Lifts: safe limit switch placement, hard stops, and emergency lockout mechanisms.

### 16.7 Additional Warehouse Automation and Benchmarking Sources

- AGILOX. “AMR Robot: Scissor Free & AI Powered.” Product benchmark for compact warehouse AMRs.
- Modula / SRS-i. “Warehouse Robotics – Types and Use Cases for Modern Warehousing.”
- “Design and Development of Warehouse Robot.” Scribd Technical Slides.

### 17 Bill of Materials (BOM)

Part ID | Part Name | Manufacturer | Quantity
1 | PCB | PCB Power | 2
2 | Power Management sys-tem | buck boost , DC AC , live battery indicator ,
3 | RealSense D455 | Intel | 1
4 | Lenovo 300 FHD Camera | Lenovo | 2
5 | Jetson AGX Xavier Devel-oper Kit | NVIDIA | 1
6 | Data Cables | various | 2
7 | RMCS 2016 | Rhino Motion Controls | 1
8 | RMCS 2012 | Rhino Motion Controls | 2
9 | USB Hub | Honeywell | 1
10 | wheels | Easymech | 2
11 | wheel coupler | Easymech | 2
12 | flexible coupler | Astro | 1
13 | caster wheel | Easymech | 1
14 | Lead Screw | | 1
15 | Batteries | ProRange | 3
16 | 3D Printed Parts | in house | 22
17 | Aluminium T links | | 24
18 | Aluminium Sheet (Parts) | in house cutting | 25
19 | L clamps | local market | 40
20 | Bearings 688 | ARB | 30
21 | kill switch | Yokins | 2
22 | limit Kill Switch | RC Hobby | 2

Table 2: Bill of Materials (Full Parts List)

### 18 CAD Models

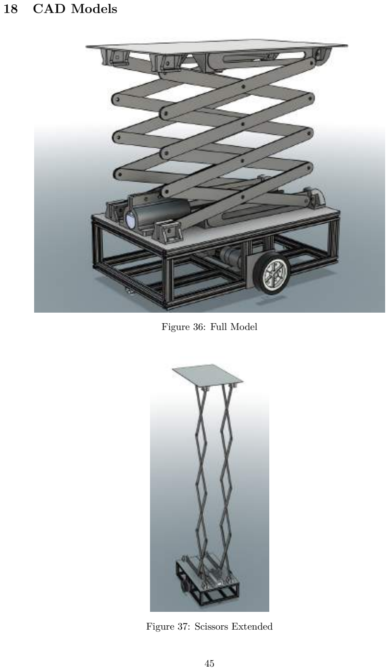
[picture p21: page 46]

Figure 36: Full Model

Figure 37: Scissors Extended

Figure 38: Chassis

Figure 39: Chassis

Figure 40: Wheel Motor Support Mount

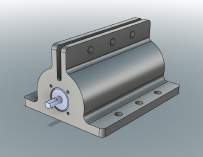
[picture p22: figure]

Figure 41: Z axis actuator motor mount

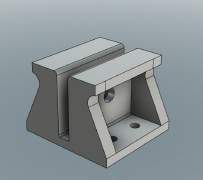
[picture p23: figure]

Figure 42: Fixed scissors mounting bottom

Figure 43: Slider mount type 1

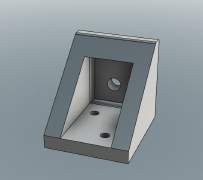
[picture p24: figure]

Figure 44: Slider mount type 2

Figure 45: Camera Mount

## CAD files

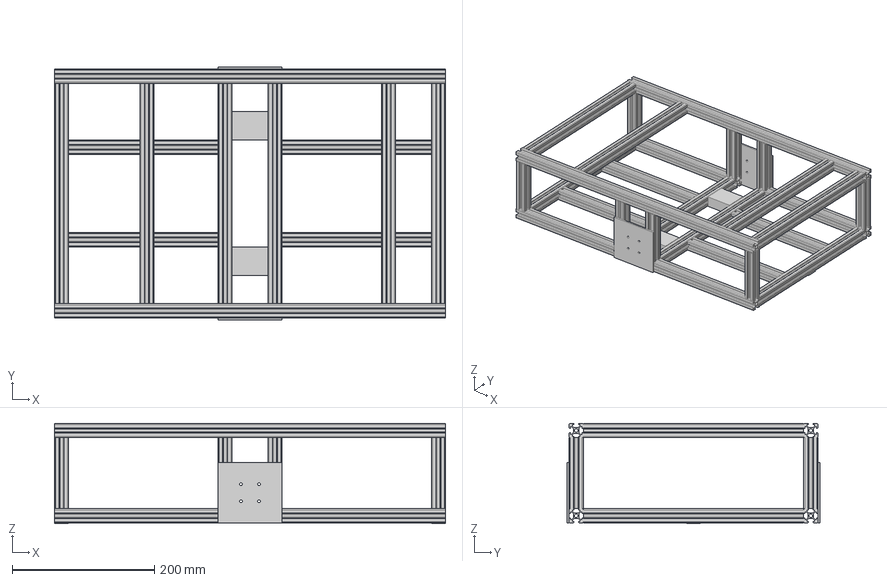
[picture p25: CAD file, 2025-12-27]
CAD_FILES/Ground_Vehicle/MAIN_BODY.step
550.0 x 356.0 x 141.0 mm

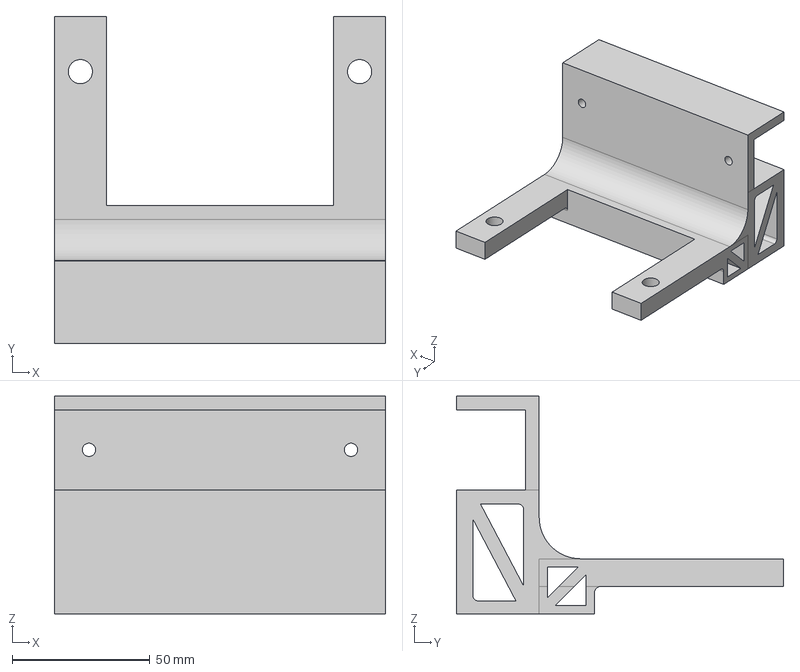
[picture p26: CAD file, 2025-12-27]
CAD_FILES/Ground_Vehicle/CAMERA_MOUNT.step
120.0 x 118.6 x 79.0 mm

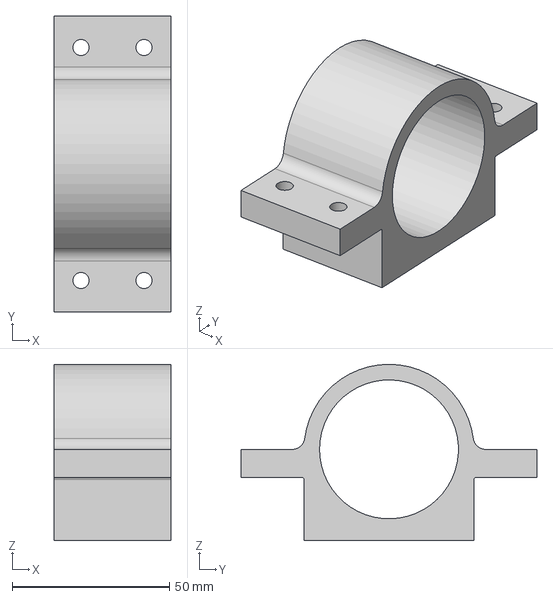
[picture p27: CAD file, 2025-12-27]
CAD_FILES/Ground_Vehicle/WHEEL_MOTOR_SUPPORT_MOUNT.step
37.0 x 94.0 x 56.0 mm
